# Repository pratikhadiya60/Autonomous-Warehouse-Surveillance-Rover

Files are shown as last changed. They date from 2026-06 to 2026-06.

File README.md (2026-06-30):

# Autonomous Warehouse Surveillance

<table align="center">
<tr>
<td align="center">
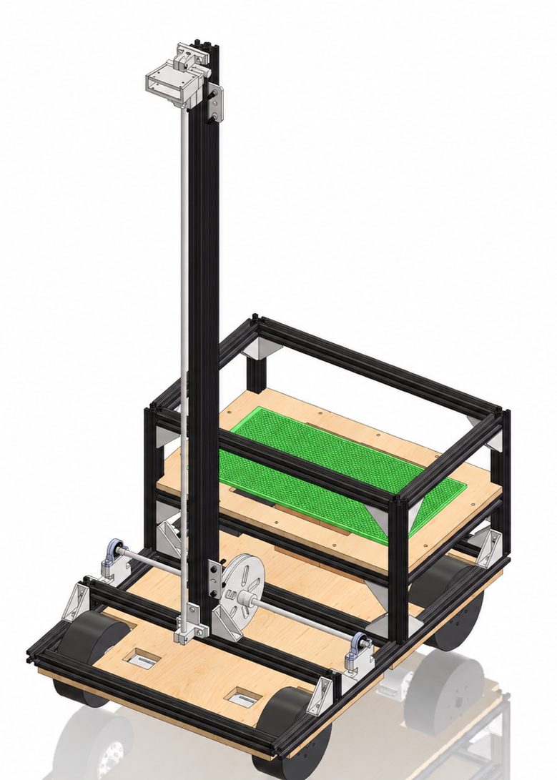
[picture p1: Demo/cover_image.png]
<br>
<b>software assembly</b><br>
</td>

<td align="center">
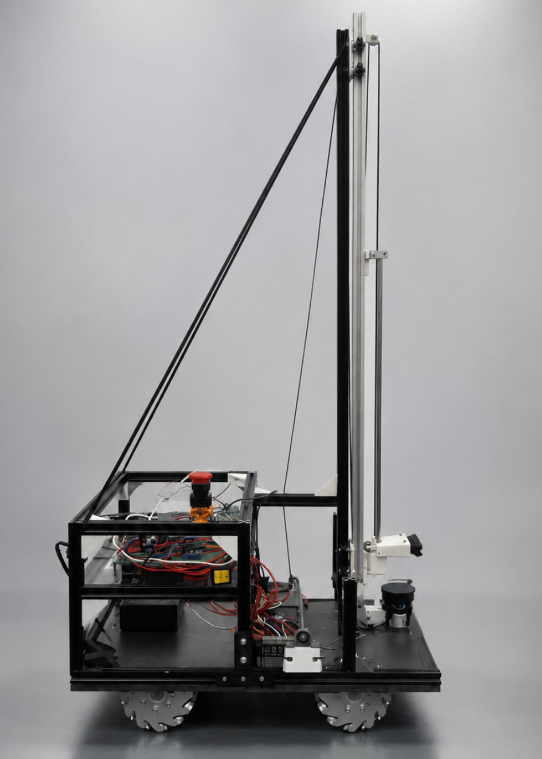
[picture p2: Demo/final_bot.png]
<br>
<b>hardware assembly</b><br>
</td>
</tr>
</table>

A ROS-based autonomous warehouse surveillance robot designed for autonomous navigation, environment mapping, obstacle avoidance, remote monitoring, and real-time data logging.

The project consists of both the complete software stack (ROS workspaces) and the hardware design files (mechanical CAD, electrical schematics, BOM, and demonstration videos).

----

# Features

- Autonomous Navigation
- SLAM Mapping
- Obstacle Avoidance & Recovery
- Remote Monitoring
- Real-Time Data Logging
- Custom Mechanical Design
- Custom Electronics Integration
- ESP32-based Motor Control
- Hardware Safety Circuit (Emergency Stop)

---

# Repository Structure

```
.
├── onboard/
│   └── ros_workspace/
│
├── offboard/
│   └── ros_workspace/
│
├── hardware/
│   ├── CAD Models
│   ├── Assemblies
│   ├── Drawings
│   ├── Lifting Mechanism
│   └── Mechanical Components
│
├── Electrical Schematics/
│
├── Demo/
│
├── Videos/
│
├── BOM_Itemized.csv
│
├── 99_m1_eternal-1.pdf
│
└── README.md
```

---

# Software

The software is divided into two ROS workspaces.

## Onboard Workspace

Location:

```
onboard/ros_workspace
```

Contains

- Robot Control
- Sensor Drivers
- Navigation
- SLAM
- Motor Interface
- Hardware Communication

---

## Offboard Workspace

Location:

```
offboard/ros_workspace
```

Contains

- Monitoring Interface
- Remote Control
- Data Logging
- Visualization
- Operator Side ROS Packages

---

# Hardware

The `hardware/` directory contains all mechanical design resources used during the project.

Contents include

- SolidWorks Parts (.SLDPRT)
- SolidWorks Assemblies (.SLDASM)
- Mechanical Drawings
- Camera Mount
- Lifting Mechanism
- Structural Components
- CAD Assemblies

Folder:

```
hardware/
```

---

# Electrical Schematics

Electrical design documents are available in

```
Electrical Schematics/
```

This includes

- High-Level Block Diagram
- ESP32 Pinout
- Motor Driver Connections
- Emergency Stop Circuit
- Motor Control Circuit
- Communication Interfaces

---

# Bill of Materials (BOM)

The complete itemized Bill of Materials is available here

```
BOM_Itemized.csv
```

The BOM includes

- Mechanical Components
- Electronics
- Fasteners
- Sensors
- Motors
- Bearings
- Structural Parts

---

# Project Report

The complete project report can be found here

```
99_m1_eternal-1.pdf
```

---

# Demonstration

## Demo

Contains screenshots and demonstration media.

```
Demo/
```

## Videos

Contains project demonstration videos including

- SLAM Mapping
- Navigation
- Obstacle Avoidance
- Vertical Mechanism
- Scanning Mechanism
- Real-Time Data Logging

```
Videos/
```

---

# Git LFS

Some large files (such as videos and CAD resources) are stored using **Git Large File Storage (Git LFS)**.

If you are cloning this repository for the first time, install Git LFS before cloning or pulling large files.

```
git lfs install
```

Git LFS will automatically download the required large files during clone or pull.

For more information:

https://git-lfs.com/

---

# Getting Started

Clone the repository

```bash
git clone https://github.com/harshitkalra03/autonomous_warehouse_surveillance.git
```

Move into the repository

```bash
cd autonomous_warehouse_surveillance
```

If using Git LFS

```bash
git lfs install
git lfs pull
```

---

# Authors

## Eternals Team – Inter IIT Tech Meet 14.0

**Institute:** Indian Institute of Technology Ropar

### Team Members

1. Pratik Hadiya
2. Syed Naqi Abbas
3. Harshit Kalra
4. Shlok Narayan Vaidya
5. Gouri Chandra Tiwary
6. Piyush Goyal

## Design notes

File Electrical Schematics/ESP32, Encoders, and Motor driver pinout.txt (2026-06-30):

#Motor Driver PWN and DIRECTION PIN ---> ESP32

FRONT_LEFT_MOTOR_PWM 14
FRONT_LEFT_MOTOR_DIR 27

FRONT_RIGHT_MOTOR_PWM 12
FRONT_RIGHT_MOTOR_DIR 26

BACK_LEFT_MOTOR_PWM 25
BACK_LEFT_MOTOR_DIR 33

BACK_RIGHT_MOTOR_PWM 32
BACK_RIGHT_MOTOR_DIR 15

#MOTOR ENCODER PINS ---> ESP32
VCC--->5V
GND--->GND (Common to ESP32)

FRONT_LEFT_ENC_PIN_A 34
FRONT_LEFT_ENC_PIN_B 35

FRONT_RIGHT_ENC_PIN_A 36
FRONT_RIGHT_ENC_PIN_B 39

BACK_LEFT_ENC_PIN_A 4
BACK_LEFT_ENC_PIN_B 16

BACK_RIGHT_ENC_PIN_A 17
BACK_RIGHT_ENC_PIN_B 18

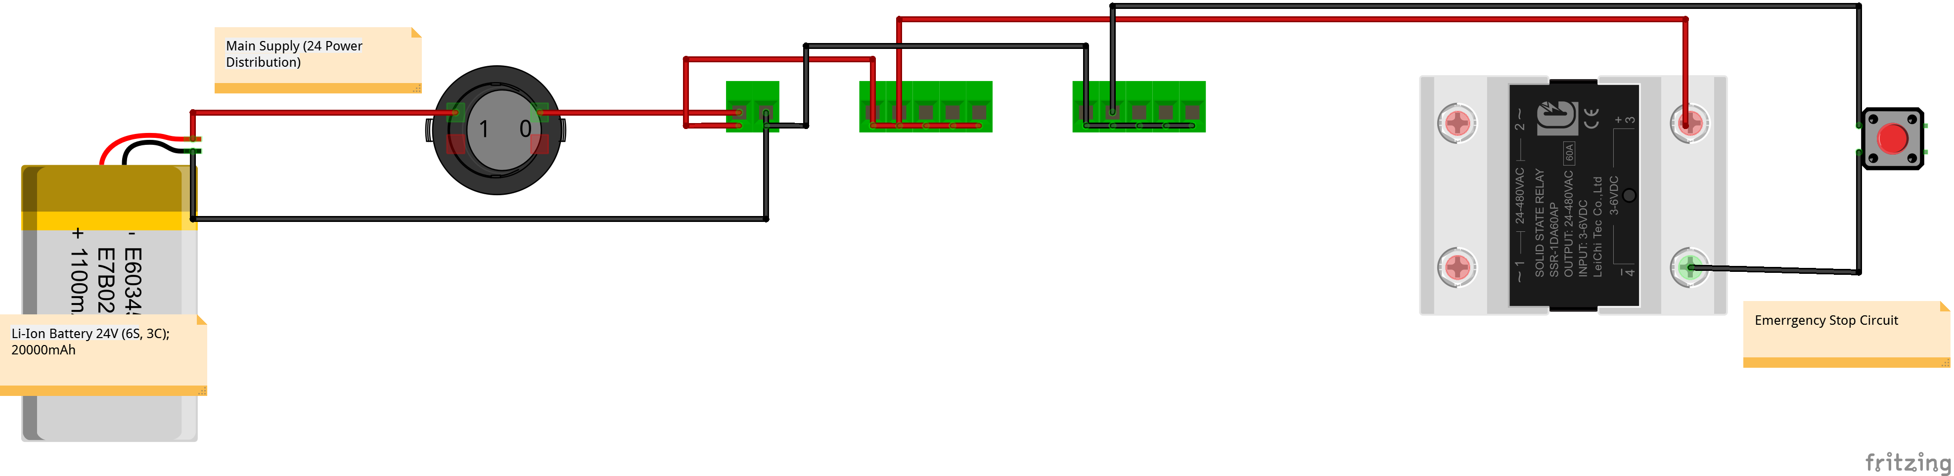
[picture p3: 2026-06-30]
Electrical Schematics/Emergency Stop Circuit (Hard Wired).png

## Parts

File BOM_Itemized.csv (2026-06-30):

BOM (Bill of Material)
Part_ID | Part_Name | Manufacturer | Quantity | Supporting Docs | Price per piece | Total
Electronics
1749034 | Raspberry Pi 5 Model 8GB RAM | Raspberry Pi | 1 | Link | 10089 | 10089
R160082 | Official Raspberry Pi Micro SD Card 32GB A2 Class | Raspberry Pi | 1 | Link | 639 | 639
Not Provided (Product Link Attached) | Ambrane Unbreakable 3A Fast Charging 1.5m Braided Type C Cable for Smartphones, Tablets & other Type C devices, 480Mbps Data Sync | Ambrane | 1 | Link | 149 | 149
1858029 | Waveshare Aluminium Alloy Case (H) for Raspberry Pi 5 | Waveshare | 1 | Link |  | 0
887613 | YDLIDAR X2 2D LiDAR Sensor | ydlidar | 1 | Link | 5812 | 5812
RMCS-5032 | Rhino 200RPM 15Kgcm 12V DC Planetary Geared Quad Encoder Servo Motor | Rhino | 4 | Link | 2183 | 8732
2777 | Cytron Enhanced 13Amp DC Motor Driver 30A peak (10 seconds) MD10C | Cytron | 4 | Link | 1167 | 4668
R122835 | 70-065-63 10A-SIBA-70-065-63 10A-Fuse, Cartridge | SIBA | 4 | Link | 14 | 56
1897066 | Fuse Holder-BF-033 | JDH | 4 | Link | 22 | 88
RMCS-1025 | Stepper Motor NEMA23 19Kgcm Torque - Economy | Supplier: Robokits India | 1 | Link | 1416 | 1416
43211 | Two Trees TB6600 Stepper Motor Driver Controller 4A 9~42V TTL 16 Micro-Step CNC 1 Axis | TOSHIBA | 1 | Link | 310 | 310
960-001587 | Logitech Brio 100 Full HD Webcam | Logitech | 1 | Link | 2995 | 2995
1242788 | Pro-Range NMC 21700 22.2V 20000mAh 3C 6S4P Li-Ion Battery Pack | Orange | 1 | Link | 10503 | 10503
R150150 | Amass XT60 Male Connector – XT60-M.G.Y | Amass | 1 | Link | 30 | 30
31506 | 20 x 30 cm Universal Double-Sided PCB Prototype Board | Imported By: Macfos Ltd | 1 | Link | 498 | 498
975683 | 24V/12V to 5V 5A Power Module DC-DC XY-3606 Power Converter | Generic | 1 | Link | 158 | 158
815794 | 200W 20A DC-DC Buck Converter Step Down Module Constant Current LED Driver Module | Imported By: Macfos Ltd | 1 | Link | 350 | 350
1510171 | XL4015 5A DC-DC Step Down Adjustable Power Supply Buck Module LED with Heatsink | XL4015 chip manufacturer: XLSEMI Import by: Macfos Ltd. | 1 | Link | 66 | 66
ROS26 | 30A 250V DPST ON-OFF Rocker Switch | Model: ZH02-Ax | 1 | Link | 91 | 91
1121394 | Red Mushroom Cap LAY37-, 11ZS 1NO 1NC DPST, Emergency Stop Push, Button Switch AC 690V 10A | Generic | 1 | Link | 99 | 99
1150699 | 6-60V SSR 100DD Relay | Fotek | 1 | Link | 793 | 793
‎esp32-wroom32-001 | Prakti ESP32 WROOM-32 NodeMCU ESP32 Development Board | PRAKTI ENTERPRISES | 1 | Link | 420 | 420
Not Provided (Product Link Attached) | Ambrane Unbreakable 60W / 3A Fast Charging 1.5m Braided Micro USB Cable for Smartphones, Tablets, Laptops & Other Micro USB Devices | Ambrane | 1 | Link | 129 | 129
R165711 | DFRobot Fermion BNO055 Intelligent 9-Axis Sensor | DFRobot | 1 | Link | 2001 | 2001
TB002-500-02BE | 2 Pin Screw Terminals | Same Sky Import by: DigiKey | 6 | Link | 35.97 | 215.82
TB002-500-03BE | 3 Pin Screw Terminals | Same Sky Import by: DigiKey | 3 | Link | 53.06 | 159.18
539050 | 1.27mm 1×40 Pin Female Single Row Header Strip | Generic | 3 | Link | 42 | 126
7450 | Male to Female Jumper Wires 40Pcs 20cm | Generic | 5 | Link | 38 | 190
1824998 | High Quality Ultra Flexible 22AWG Silicone Wire – Red | Import by: Macfos Ltd | 2 | Link | 18 | 36
R179511 | High Quality Ultra Flexible 16AWG Silicone Wire – red | Import by: Macfos Ltd | 2 | Link | 49 | 98
‎BE 487474 | BELLOX 560Pieces Heat Shrink Tubing 2:1- Electrical Wire Cable Sleeving Wrap, Cable Wrap Assortment Electric Insulation Heat Shrink Tube Kit with Box(5 colors/12 Sizes) Black, Red, Blue,Yellow,Green | Bellox Enterprise | 1 | Link | 315 | 315
18279 | Nylon Cable Zip Ties 150 mm White (100pcs) | Generic | 1 | Link | 72 | 72
 |  |  |  |  | Total Cost | 51304
Mobile base Frame
RMCS-3057 | Motor Mount | Rhino | 4 | Link | 123.9 | 495.6
44223 | EasyMech 127mm Aluminium Mecanum Bearing Type Roller Wheels (2 Left and 2 Right) | EasyMech | 1 | Link | 13368.96 | 13368.96
29680 | EasyMech Bracket for NEMA 23 Stepper Motor Bend Sturdy Mount | EasyMech | 1 | Link | 239 | 239
886058 | EasyMech1500 mm 20X20 4T Slot Aluminium Extrusion Profile (Silver) | EasyMech | 8 | Link | 660 | 5280
1166276 | EasyMech Aluminium Alloy Built-In Corner Slot Connector For 20 Series Profile With Grub – Pack of 4 | EasyMech | 1 | Link | 253 | 253
 |  |  |  |  | Total Cost | 19636.56
Vertical Scanning Mechanism
316744 | eSUN PLA+ 1.75mm 3D Printing Filament 1kg-White | eSun | 2 | Link | 1270 | 2540
844726 | EasyMech M4 MS Sliding T Nut For 2020 Series Aluminium Extrusion Profile – 10 Pcs | EasyMech | 5 | Link | 224 | 1120
52022 | 10M GT2 Width 6mm Black Open Timing Belt | Import by: Macfos Ltd. | 1 | Link | 882 | 882
RKI-2167 | Aluminum GT2 Timing Idler Pulley For 6mm Belt 20 Tooth 5mm Bore | Import by: Macfos Ltd. | 4 | Link | 105.2 | 420.8
Fdit8utzsr0cwg1430 | Fdit V Groove Pulley, Wear- with 20 Pieces of Wheels V-Type Pulley | Fdit | 1 | Link | 2928 | 2928
52303 | SC8UU 8 mm Linear Ball Bearing Slide | Techtonics | 1 | Link | 99 | 99
52748 | Two Trees SH8A SK8 8mm linear bearing rail support XYZ Shaft Table CNC Router (2Pcs) | Two Trees | 1 | Link | 104 | 104
RKI-6024 | Astro Super Smooth Hard Chrome plated 8mm diameter carbon steel rod 1000mm long | Astro Brand | 2 | Link | 330.4 | 660.8
457677 | 625RS Rubber Sealed Ball Bearing Miniature Bearing 5 x 16 x 5 mm 2 pcs | Generic | 2 | Link | 48 | 96
Not Provided (OnlyScrews Product Link Attached) | Phillips Pan Head Assorted Screw Pack M3, M4 & M5 (SS304) | OnlyScrews | 2 | Link | 840 | 1680
KP08 | KP08 8mm Bore Inner Ball Mounted Pillow Block Insert Bearing | OnlyScrews | 2 | Link | 150 | 300
 |  |  |  |  | Total Cost | 10830.6
 |  |  |  |  | Prototype Cost | 81771.16
 | Estimated Shipping time | Subject to courier service; generally 3–7 business days for domestic orders

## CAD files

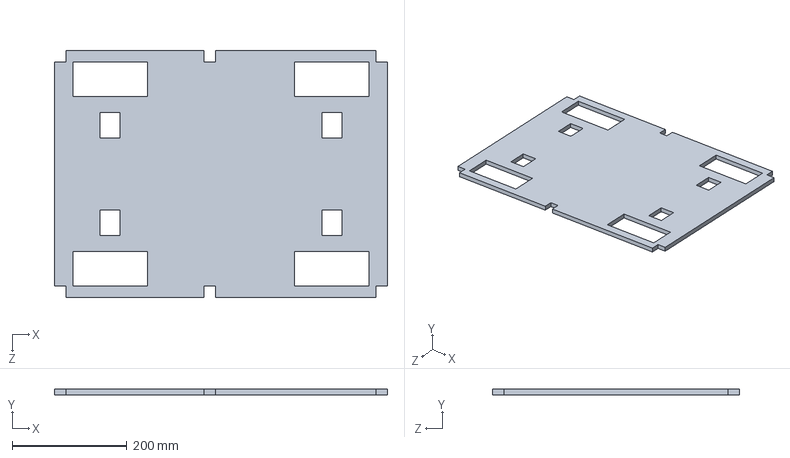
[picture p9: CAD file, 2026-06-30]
hardware/bot base/base/Sunboard.SLDPRT
580.0 x 10.0 x 430.0 mm

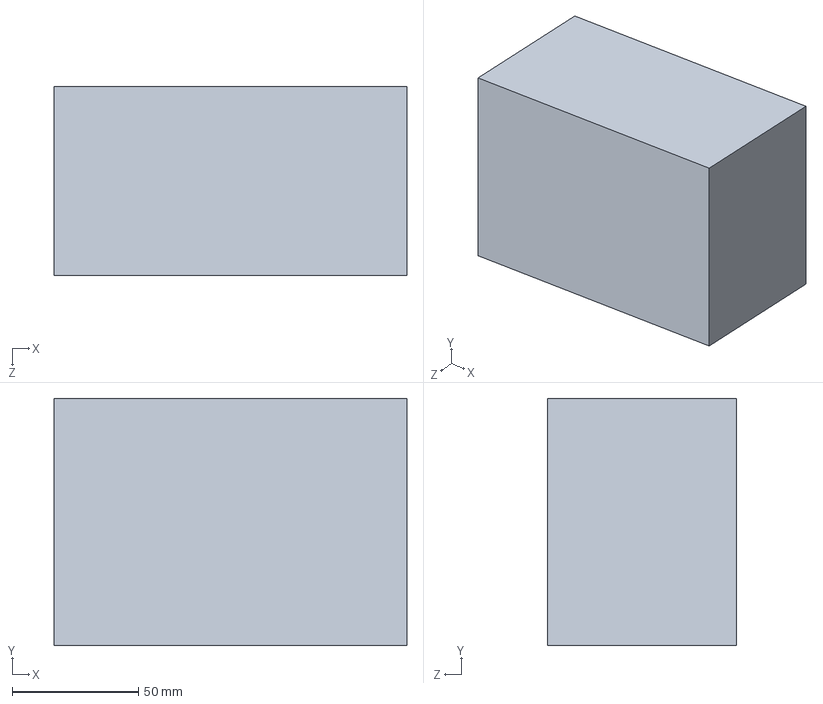
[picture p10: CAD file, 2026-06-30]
hardware/bot base/Battery.SLDPRT
140.0 x 98.0 x 75.0 mm

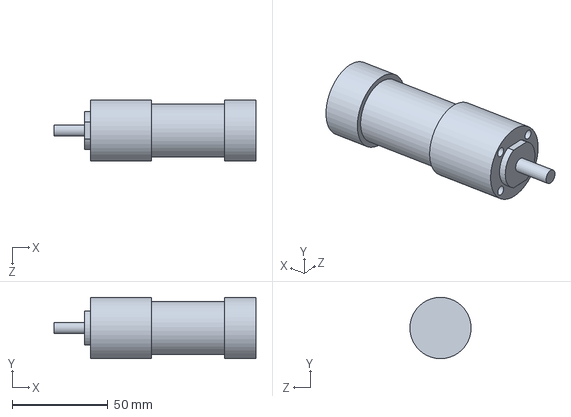
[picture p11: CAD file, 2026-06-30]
hardware/bot base/driving system/IG32 Motor.SLDPRT
105.5 x 32.0 x 31.9 mm

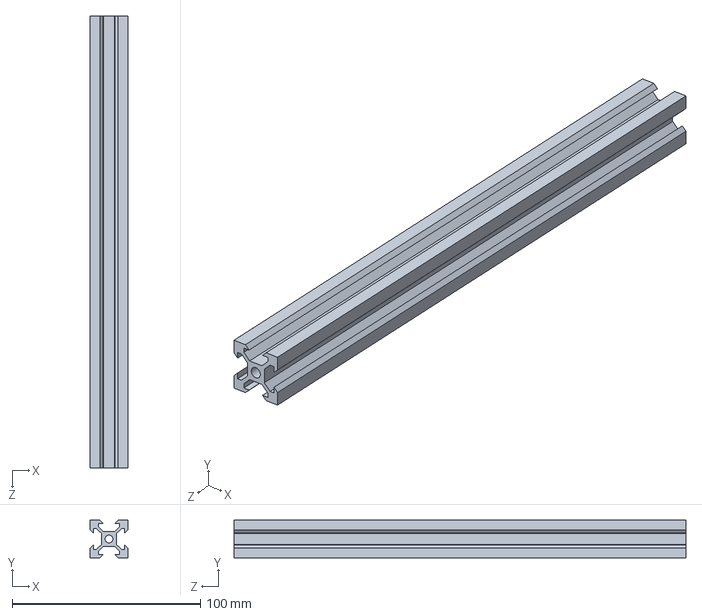
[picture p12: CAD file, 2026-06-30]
hardware/bot base/extrusion profile/layer 1 hight.SLDPRT
20.0 x 20.0 x 240.0 mm

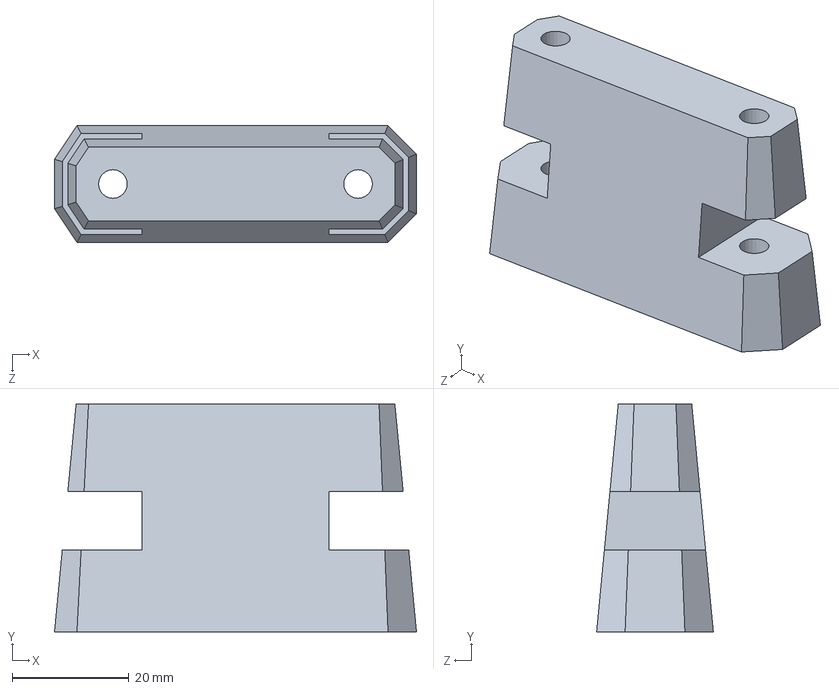
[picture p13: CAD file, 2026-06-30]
hardware/lifting mechanisum/mechanisum base/bearing stand.SLDPRT
62.0 x 39.0 x 20.0 mm

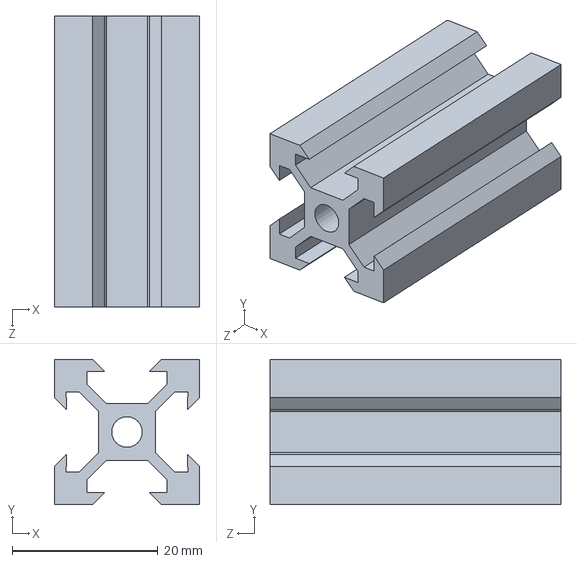
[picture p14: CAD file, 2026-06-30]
hardware/lifting mechanisum/mechanisum base/extrusion frame/Aluminium Profile for hight.SLDPRT
20.0 x 20.0 x 40.0 mm

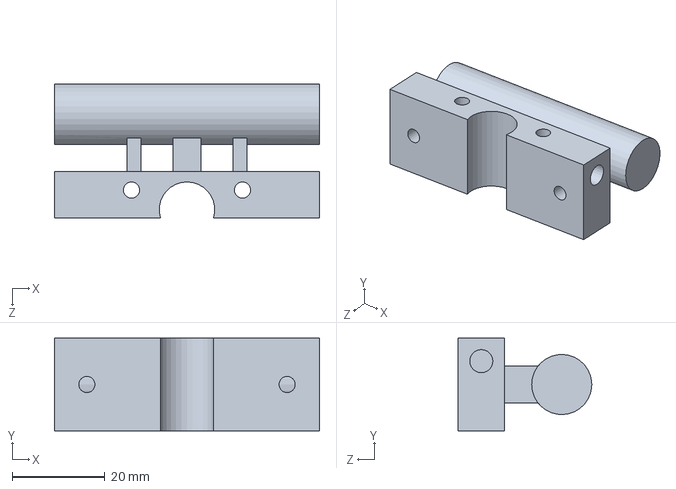
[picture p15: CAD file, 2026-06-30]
hardware/lifting mechanisum/mechanisum/camera mount/camera mount new part 2.SLDPRT
57.3 x 20.1 x 28.9 mm

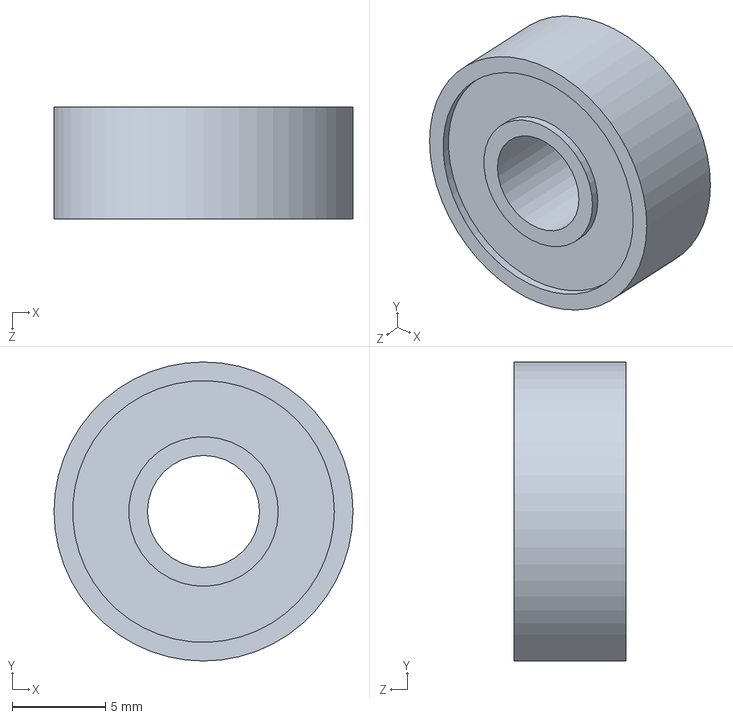
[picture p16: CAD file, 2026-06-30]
hardware/lifting mechanisum/mechanisum/glider/bearing.SLDPRT
16.0 x 16.0 x 6.00 mm

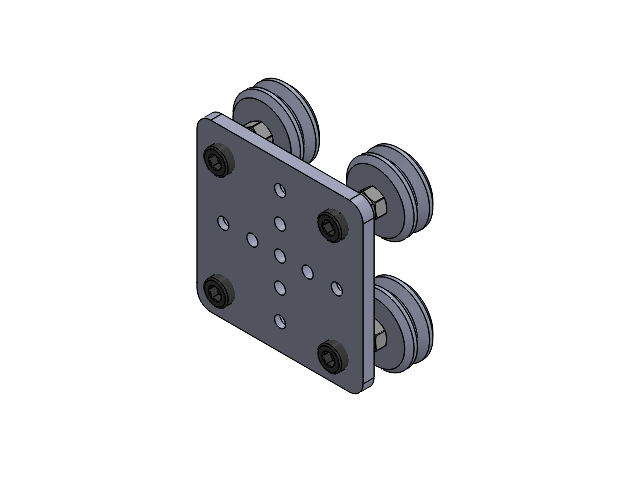
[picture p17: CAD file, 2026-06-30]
hardware/lifting mechanisum/mechanisum/mini roller.SLDASM
upgraded minirollar plate
M5x25mm l key bolt x 4
M5 nut x 12
Delrin V Wheel x 4
bearing x 4

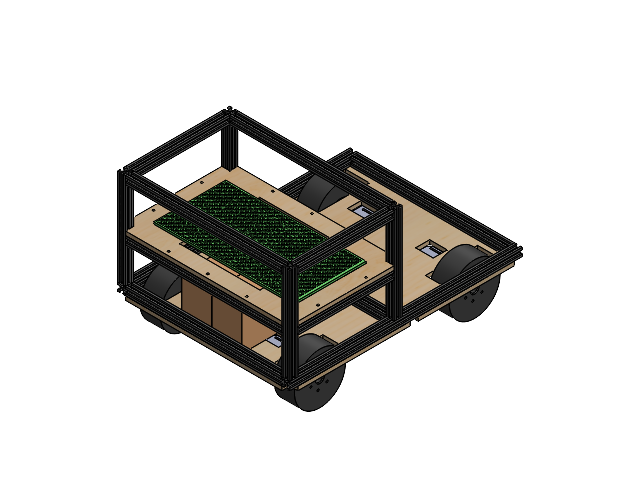
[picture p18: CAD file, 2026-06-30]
hardware/bot base.SLDASM
layer 1 width x 7
layer 1 length x 2
layer 1 hight x 4
layer 2 length x 4
Sunboard
Vertical_Sunboard
Perfboard
Motor Mount_IG32 x 4
Wheel Mount_6mm x 4
Wheels x 4
IG32 Motor x 4
Battery x 2

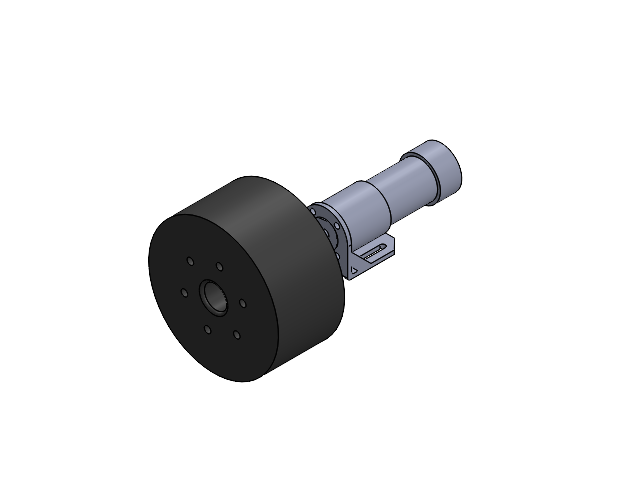
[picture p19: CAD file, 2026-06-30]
hardware/bot base/wheel+motor.SLDASM
Motor Mount_IG32
Wheel Mount_6mm
Wheels
IG32 Motor

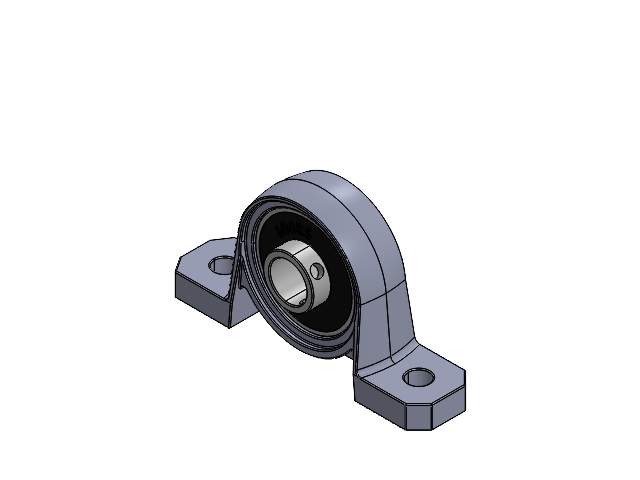
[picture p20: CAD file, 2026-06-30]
hardware/lifting mechanisum/mechanisum base/KP08 Flange Bearing.SLDASM
KP08_1.STEP
608RS.STEP

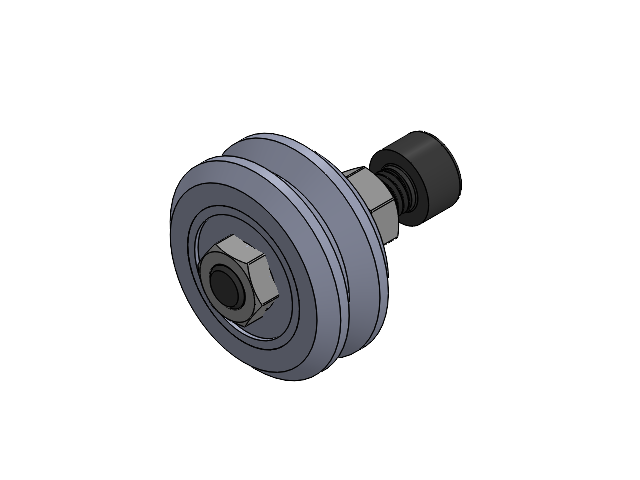
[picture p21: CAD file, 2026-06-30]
hardware/lifting mechanisum/mechanisum/glider/rollar assembly.SLDASM
M5x25mm l key bolt
M5 nut x 3
Delrin V Wheel
bearing

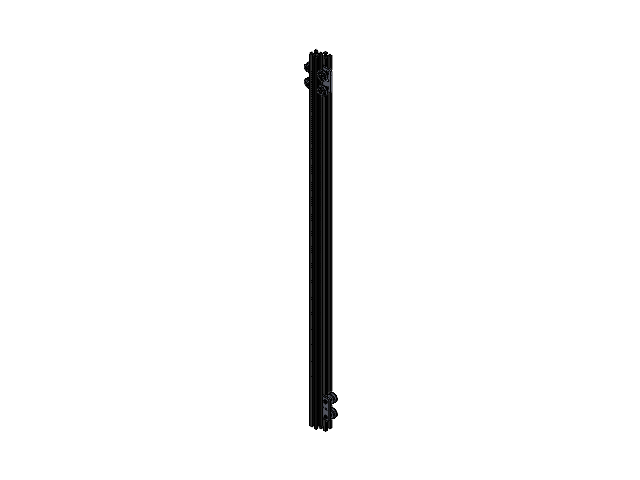
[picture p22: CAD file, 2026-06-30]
hardware/lifting mechanisum/mechanisum/rollar + 2020.SLDASM
Aluminium Profile for vertical part x 2
upgraded minirollar plate x 2
M5x25mm l key bolt x 8
M5 nut x 24
Delrin V Wheel x 8
bearing x 8

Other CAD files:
hardware/lifting mechanisum.SLDASM
hardware/lifting mechanisum/mechanisum base/mechanisum base.SLDASM
hardware/lifting mechanisum/mechanisum/mechanisum.SLDASM
hardware/lifting mechanisum/mechanisum/new camera mount.SLDASM
hardware/bot base/base/Perfboard.SLDPRT
hardware/bot base/base/Vertical_Sunboard.SLDPRT
hardware/bot base/driving system/Motor Mount_IG32.SLDPRT
hardware/bot base/driving system/Wheel Mount_6mm.SLDPRT
hardware/bot base/driving system/Wheels.SLDPRT
hardware/bot base/extrusion profile/layer 1 length.SLDPRT
hardware/bot base/extrusion profile/layer 1 width.SLDPRT
hardware/bot base/extrusion profile/layer 2 length.SLDPRT
hardware/corner bracket.SLDPRT
hardware/lifting mechanisum/mechanisum base/extrusion frame/Aluminium Profile for length.SLDPRT
hardware/lifting mechanisum/mechanisum base/extrusion frame/Aluminium Profile for width.SLDPRT
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

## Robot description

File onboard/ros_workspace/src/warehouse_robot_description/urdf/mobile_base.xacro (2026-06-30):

<?xml version="1.0"?>
<robot xmlns:xacro="http://www.ros.org/wiki/xacro">

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
<link name="base_link">
  <inertial>
    <mass value="0.001" />  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
  </inertial>
</link>

<link name="base_footprint">
  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
</link>

<joint name="base_link_to_base_footprint" type="fixed">
  <parent link="base_link"/>
  <child link="base_footprint"/>
  <origin xyz="0 0 0" rpy="0 0 0"/>
</joint>

<link name="lidar_link">
  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
  <inertial>
    <mass value="${lidar_mass}" />
    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
  </inertial>
</link>

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

<link name="plate_link">
  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
  <inertial>
    <mass value="${base_plate_mass}" />
    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
  </inertial>
</link>

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
<link name="top_plate_link">
  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
  <inertial>
    <mass value="${top_plate_mass}" />
    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
  </inertial>
</link>

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
<link name="middle_plate_link">
  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
  <inertial>
    <mass value="${top_plate_mass}" />
    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
  </inertial>
</link>

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
<link name="base_rod_front">
  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
  <inertial>
    <mass value="${base_rod_mass}" />
    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
  </inertial>
</link>

<link name="base_rod_back">
  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
  <inertial>
    <mass value="${base_rod_mass}" />
    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
  </inertial>
</link>

<link name="base_rod_right">
  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
  <inertial>
    <mass value="${base_rod_mass}" />
    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
  </inertial>
</link>

<link name="base_rod_left">
  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
  <inertial>
    <mass value="${base_rod_mass}" />
    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
  </inertial>
</link>

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
<link name="vertical_rod_front_right">
  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
  <inertial>
    <mass value="${vertical_rod_mass}" />
    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
  </inertial>
</link>

<link name="vertical_rod_front_left">
  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
  <inertial>
    <mass value="${vertical_rod_mass}" />
    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
  </inertial>
</link>

<link name="vertical_rod_rear_right">
  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
  <inertial>
    <mass value="${vertical_rod_mass}" />
    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
  </inertial>
</link>

<link name="vertical_rod_rear_left">
  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
  <inertial>
    <mass value="${vertical_rod_mass}" />
    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
  </inertial>
</link>

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
<link name="frame_top_front">
  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
  <inertial>
    <mass value="${frame_bar_mass}" />
    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
  </inertial>
</link>

<link name="frame_top_back">
  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
  <inertial>
    <mass value="${frame_bar_mass}" />
    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
  </inertial>
</link>

<link name="frame_top_left">
  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
  <inertial>
    <mass value="${frame_bar_mass}" />
    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
  </inertial>
</link>

<link name="frame_top_right">
  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
  <inertial>
    <mass value="${frame_bar_mass}" />
    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
  </inertial>
</link>

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
<link name="frame_middle_front">
  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
  <inertial>
    <mass value="${frame_bar_mass}" />
    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
  </inertial>
</link>

<link name="frame_middle_back">
  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
  <inertial>
    <mass value="${frame_bar_mass}" />
    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
  </inertial>
</link>

<link name="frame_middle_left">
  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
  <inertial>
    <mass value="${frame_bar_mass}" />
    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
  </inertial>
</link>

<link name="frame_middle_right">
  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
  <inertial>
    <mass value="${frame_bar_mass}" />
    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
  </inertial>
</link>

<joint name="base_to_plate" type="fixed">
  <parent link="base_link" />
  <child link="plate_link" />
  <origin xyz="0 0 ${-plate_thickness/2}" rpy="0 0 0" />
</joint>

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
<joint name="base_to_top_plate" type="fixed">
  <parent link="base_link" />
  <child link="top_plate_link" />
  <origin xyz="-0.15 0 ${base_height + bar_height/2 + plate_thickness/2}" rpy="0 0 0" />
  
</joint>

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
<joint name="base_to_middle_plate" type="fixed">
  <parent link="base_link" />
  <child link="middle_plate_link" />
  <origin xyz="-0.15 0 ${0.14 + bar_height/2 + plate_thickness/2}" rpy="0 0 0" />
</joint>

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
<joint name="base_to_middle_front" type="fixed">
  <parent link="base_link" />
  <child link="frame_middle_front" />
  <origin xyz="-0.15 ${base_width/2 - bar_width/2} 0.14" rpy="0 0 0" />
</joint>

<joint name="base_to_middle_back" type="fixed">
  <parent link="base_link" />
  <child link="frame_middle_back" />
  <origin xyz="-0.15 ${-base_width/2 + bar_width/2} 0.14" rpy="0 0 0" />
</joint>

<joint name="base_to_middle_right" type="fixed">
  <parent link="base_link" />
  <child link="frame_middle_right" />
  <origin xyz="-0.01 0 0.14" rpy="0 0 0" />
</joint>

<joint name="base_to_middle_left" type="fixed">
  <parent link="base_link" />
  <child link="frame_middle_left" />
  <origin xyz="-0.29 0 0.14" rpy="0 0 0" />
</joint>


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

<joint name="base_link_to_lidar" type="fixed">
  <parent link="base_link" />
  <child link="lidar_link" />
  <origin xyz="0.27 0 0.02" rpy="3.14 0 -1.57" />
</joint>

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
<xacro:macro name="wheel_link" params="prefix">
  <link name="${prefix}_wheel_link">
    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
    <inertial>
      <mass value="${wheel_mass}" />
      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
    </inertial>
  </link>
</xacro:macro>

<xacro:wheel_link prefix="front_right" />
<xacro:wheel_link prefix="front_left" />
<xacro:wheel_link prefix="rear_right" />
<xacro:wheel_link prefix="rear_left" />

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
<link name="imu_link">
  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
  <inertial>
    <mass value="0.1" />  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
  </inertial>
</link>

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
<link name="camera_support_rod_link">
  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
  <inertial>
    <mass value="0.5" />
    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
  </inertial>
</link>

<link name="camera_link">
  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
  <inertial>
    <mass value="0.05" />
    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
  </inertial>
</link>

<link name="camera_rgb_frame">
  <inertial>
    <mass value="1e-5" />
    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
  </inertial>
</link>


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
<joint name="base_to_imu" type="fixed">
  <parent link="base_link" />
  <child link="imu_link" />
  <origin xyz="0 0 0.0025" rpy="0 0 0" />  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
</joint>



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
<joint name="base_to_base_rod_front" type="fixed">
  <parent link="base_link" />
  <child link="base_rod_front" />
  <origin xyz="0 ${base_width/2 - rod_width/2} ${rod_height/2}" rpy="0 0 0" />
</joint>

<joint name="base_to_base_rod_back" type="fixed">
  <parent link="base_link" />
  <child link="base_rod_back" />
  <origin xyz="0 ${-base_width/2 + rod_width/2} ${rod_height/2}" rpy="0 0 0" />
</joint>

<joint name="base_to_base_rod_right" type="fixed">
  <parent link="base_link" />
  <child link="base_rod_right" />
  <origin xyz="${base_length/2 - rod_width/2} 0 ${rod_height/2}" rpy="0 0 0" />
</joint>

<joint name="base_to_base_rod_left" type="fixed">
  <parent link="base_link" />
  <child link="base_rod_left" />
  <origin xyz="${-base_length/2 + rod_width/2} 0 ${rod_height/2}" rpy="0 0 0" />
</joint>

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
<joint name="base_to_vertical_rod_front_right" type="fixed">
  <parent link="base_link" />
  <child link="vertical_rod_front_right" />
  <origin xyz="-0.01 ${base_width/2 - bar_width/2} ${base_height/2}" rpy="0 0 0" />
</joint>

<joint name="base_to_vertical_rod_front_left" type="fixed">
  <parent link="base_link" />
  <child link="vertical_rod_front_left" />
  <origin xyz="-0.29 ${base_width/2 - bar_width/2} ${base_height/2}" rpy="0 0 0" />
</joint>

<joint name="base_to_vertical_rod_rear_right" type="fixed">
  <parent link="base_link" />
  <child link="vertical_rod_rear_right" />
  <origin xyz="-0.01 ${-base_width/2 + bar_width/2} ${base_height/2}" rpy="0 0 0" />
</joint>

<joint name="base_to_vertical_rod_rear_left" type="fixed">
  <parent link="base_link" />
  <child link="vertical_rod_rear_left" />
  <origin xyz="-0.29 ${-base_width/2 + bar_width/2} ${base_height/2}" rpy="0 0 0" />
</joint>

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
<joint name="base_to_top_front" type="fixed">
  <parent link="base_link" />
  <child link="frame_top_front" />
  <origin xyz="-0.15 ${base_width/2 - bar_width/2} ${base_height}" rpy="0 0 0" />
</joint>

<joint name="base_to_top_back" type="fixed">
  <parent link="base_link" />
  <child link="frame_top_back" />
  <origin xyz="-0.15 ${-base_width/2 + bar_width/2} ${base_height}" rpy="0 0 0" />
</joint>

<joint name="base_to_top_right" type="fixed">
  <parent link="base_link" />
  <child link="frame_top_right" />
  <origin xyz="-0.01 0 ${base_height}" rpy="0 0 0" />
</joint>

<joint name="base_to_top_left" type="fixed">
  <parent link="base_link" />
  <child link="frame_top_left" />
  <origin xyz="-0.29 0 ${base_height}" rpy="0 0 0" />
</joint>

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
<joint name="base_front_right_wheel_joint" type="continuous">
  <parent link="base_link" />
  <child link="front_right_wheel_link" />
  <origin xyz="0.15 -0.165 -0.025" rpy="0 0 0" />
  <axis xyz="0 1 0" />
</joint>
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

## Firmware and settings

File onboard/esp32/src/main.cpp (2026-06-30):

#define USE_BASE      // Enable the base controller code
#undef USE_SERVOS     // Disable use of PWM servos

#define BAUDRATE     115200
#define MAX_PWM        255

#if defined(ARDUINO) && ARDUINO >= 100
#include "Arduino.h"
#else
#include "WProgram.h"
#endif

#include "commands.h"

#define ARDUINO_ENC_COUNTER

   /* L298 Motor driver*/
#define L298_MOTOR_DRIVER

#ifdef USE_BASE
  #include "motor_driver.h"
  #include "encoder_driver.h"
  #include "diff_controller.h"
  #include "stepper_driver.h"

  #define PID_RATE           30     // Hz
  const int PID_INTERVAL = 1000 / PID_RATE;
  unsigned long nextPID = PID_INTERVAL;
  #define AUTO_STOP_INTERVAL 100
  long lastMotorCommand = AUTO_STOP_INTERVAL;

#endif

int arg = 0;
int my_index = 0;
char chr;
char cmd;
char argv1[16], argv2[16], argv3[16], argv4[16];
long arg1, arg2, arg3, arg4;

void resetCommand() {
  cmd = NULL;
  memset(argv1, 0, sizeof(argv1));
  memset(argv2, 0, sizeof(argv2));
  memset(argv3, 0, sizeof(argv3));
  memset(argv4, 0, sizeof(argv4));
  arg1 = arg2 = arg3 = arg4 = 0;
  arg = 0;
  my_index = 0;
}

void runCommand() {
  int i = 0;
  char *p = argv1;
  char *str;
  int pid_args[4];
  arg1 = atoi(argv1);
  arg2 = atoi(argv2);
  arg3 = atoi(argv3);
  arg4 = atoi(argv4);

  switch(cmd) {
#ifdef USE_BASE
  case READ_ENCODERS:
    Serial.print(readEncoder(FRONT_LEFT));
    Serial.print(" ");
    Serial.print(readEncoder(FRONT_RIGHT));
    Serial.print(" ");
    Serial.print(readEncoder(BACK_LEFT));
    Serial.print(" ");
    Serial.println(readEncoder(BACK_RIGHT));
    break;
  case RESET_ENCODERS:
    resetEncoders();
    resetPID();
    Serial.println("OK");
    break;
  case MOTOR_SPEEDS:
    lastMotorCommand = millis();
    if (arg1 == 0 && arg2 == 0 && arg3 == 0 && arg4 == 0) {
      setMotorSpeeds(0, 0, 0, 0);
      resetPID();
      moving = 0;
    } else moving = 1;
    front_leftPID.TargetTicksPerFrame = arg1;
    front_rightPID.TargetTicksPerFrame = arg2;
    back_leftPID.TargetTicksPerFrame = arg3;
    back_rightPID.TargetTicksPerFrame = arg4;
    Serial.println("OK");
    break;
  case MOTOR_RAW_PWM:
    lastMotorCommand = millis();
    resetPID();
    moving = 0;
    setMotorSpeeds(arg1, arg2, arg3, arg4);
    Serial.println("OK");
    break;
  case UPDATE_PID:
    while ((str = strtok_r(p, ":", &p)) != NULL) {
       pid_args[i] = atoi(str);
       i++;
    }
    Kp = pid_args[0];
    Kd = pid_args[1];
    Ki = pid_args[2];
    Ko = pid_args[3];
    Serial.println("OK");
    break;
  case STEPPER_STEP_POSITIVE:
    stepMotor(arg1, true);
    setMotorSpeeds(0, 0, 0, 0);
    Serial.println("OK");
    break;
  case STEPPER_STEP_NEGATIVE:
    stepMotor(arg1, false);
    setMotorSpeeds(0, 0, 0, 0);
    Serial.println("OK");
    break;
#endif
  default:
    Serial.println("Invalid Command");
    break;
  }

  return;
}

/* ===================== Hardware Interrupts for ESP32 ===================== */

void setup() {
  Serial.begin(BAUDRATE);

#ifdef USE_BASE
#ifdef ARDUINO_ENC_COUNTER
  // Set encoder pins
  pinMode(FRONT_LEFT_ENC_PIN_A, INPUT_PULLUP);
  pinMode(FRONT_LEFT_ENC_PIN_B, INPUT_PULLUP);
  pinMode(FRONT_RIGHT_ENC_PIN_A, INPUT_PULLUP);
  pinMode(FRONT_RIGHT_ENC_PIN_B, INPUT_PULLUP);
  pinMode(BACK_LEFT_ENC_PIN_A, INPUT_PULLUP);
  pinMode(BACK_LEFT_ENC_PIN_B, INPUT_PULLUP);
  pinMode(BACK_RIGHT_ENC_PIN_A, INPUT_PULLUP);
  pinMode(BACK_RIGHT_ENC_PIN_B, INPUT_PULLUP);
    // Stepper pins
  pinMode(STEPPER_STEP_PIN, OUTPUT);
  pinMode(STEPPER_DIR_PIN, OUTPUT);

  // Attach hardware interrupts
  attachInterrupt(digitalPinToInterrupt(FRONT_LEFT_ENC_PIN_A), frontLeftISR, CHANGE);
  attachInterrupt(digitalPinToInterrupt(FRONT_RIGHT_ENC_PIN_A), frontRightISR, CHANGE);
  attachInterrupt(digitalPinToInterrupt(BACK_LEFT_ENC_PIN_A), backLeftISR, CHANGE);
  attachInterrupt(digitalPinToInterrupt(BACK_RIGHT_ENC_PIN_A), backRightISR, CHANGE);
#endif

  initMotorController();
  resetPID();
#endif

  pinMode(FRONT_LEFT_MOTOR_DIR, OUTPUT);
  pinMode(FRONT_RIGHT_MOTOR_DIR, OUTPUT);
  pinMode(BACK_LEFT_MOTOR_DIR, OUTPUT);
  pinMode(BACK_RIGHT_MOTOR_DIR, OUTPUT);
}

void loop() {
  while (Serial.available() > 0) {
    chr = Serial.read();

    if (chr == 13) {
        if (arg == 1) argv1[my_index] = NULL;
        else if (arg == 2) argv2[my_index] = NULL;
        else if (arg == 3) argv3[my_index] = NULL;
        else if (arg == 4) argv4[my_index] = NULL;

        runCommand();
        resetCommand();
    }
    else if (chr == ' ') {
        if (arg == 0) arg = 1;
        else if (arg == 1) { argv1[my_index] = NULL; arg = 2; my_index = 0; }
        else if (arg == 2) { argv2[my_index] = NULL; arg = 3; my_index = 0; }
        else if (arg == 3) { argv3[my_index] = NULL; arg = 4; my_index = 0; }
        continue;
    }
    else {
        if (arg == 0) cmd = chr;
        else if (arg == 1) argv1[my_index++] = chr;
        else if (arg == 2) argv2[my_index++] = chr;
        else if (arg == 3) argv3[my_index++] = chr;
        else if (arg == 4) argv4[my_index++] = chr;
    }
  }

#ifdef USE_BASE
  if (millis() > nextPID) {
    updatePID();
    nextPID += PID_INTERVAL;
  }

  if ((millis() - lastMotorCommand) > AUTO_STOP_INTERVAL) {
    setMotorSpeeds(0, 0, 0, 0);
    moving = 0;
  }
#endif
}
